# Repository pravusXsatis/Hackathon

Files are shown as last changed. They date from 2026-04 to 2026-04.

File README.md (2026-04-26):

# CPR Trainer — IDEA Hacks 2026

> **Theme: A Brighter Tomorrow** | **Subcategory: Educate the Future**
>
> Affordable, hands-on CPR practice: anywhere, anytime, no mannequin required.
>
> ⚠️ Training only — not a certified medical device.

---

## Inspiration

Cardiac arrest strikes more than 350,000 people outside of hospitals in the United States every year. Immediate bystander CPR can double or triple a victim's chance of survival, yet the vast majority of people have never practiced it. The barrier isn't awareness; it's access. Certified CPR training requires scheduling a class, traveling to a facility, and working with expensive mannequins that cost hundreds to thousands of dollars per unit.

We built the CPR Trainer to remove that barrier entirely. It is a wrist-worn device that turns any springy surface, like a couch cushion, a foam mat, a folded blanket, into a CPR practice station. A user connects their phone to the device's own Wi-Fi network, opens the dashboard in a browser, and receives real-time, per-compression coaching with zero setup friction and zero ongoing cost. This project gives hands-on CPR practice on a low cost portable setup.

---

## Why This Is an "Educate the Future" Project

- **Enhances how people learn CPR.** Rather than watching a video or attending a one-time class, the user gets immediate, quantified feedback on every compression, rate, force, and full release, forming correct muscle memory through repetition.
- **Integrates into daily life.** The device requires no mannequin, no facility, and no internet connection. Practice happens wherever someone already is, with the phone already in their pocket.
- **Unique educational approach.** A calibration step personalizes the feedback thresholds to the individual user and surface. This makes the coaching adaptive, not one-size-fits-all.
- **Intuitive and engaging.** The dashboard opens instantly in any browser. The guided calibration walks users through setup in under 30 seconds with a countdown UI. Feedback is immediate, plain-language, and per-compression.

---

## What It Does

The CPR Trainer wristband reads an FSR (Force-Sensitive Resistor) and ADXL335 accelerometer on an ESP32. The ESP32 broadcasts its own Wi-Fi access point, named `CPR_Trainer` (password: `cpr2026!`); the user connects their phone or laptop to that network and opens the on-device dashboard at `http://192.168.4.1` — no app install, no internet. The dashboard reads live data and shows rate, relative force, and motion quality.

### Live feedback on every compression

| Label | What it means |
|---|---|
| **Good compression** | Peak force is within the user's calibrated target range |
| **Push harder** | Peak force is below 60 % of the calibrated target |
| **Too hard** | Peak force exceeds 130 % of the calibrated target |
| **Release fully** | Force did not drop back to baseline — leaning detected |
| **Start compressions** | Idle state, ready to begin |

### Dashboard at a glance

- **Compression rate gauge** — live CPM needle against the AHA target band of 100–120 CPM
- **Relative-force trend graph** — scrolling plot of the last 100 force readings with a target-force reference line
- **Metric cards** — compression count, rate, raw force, relative force, target force, and recoil threshold
- **Motion quality score** — sum of corrected accelerometer magnitudes (|X| + |Y| + |Z|) as a wrist-form indicator
- **Guided calibration modal** — 3-step flow with countdown UI, "Ready / Set / Go" cues, and recoil confirmation

---

## How We Built It

### Hardware

| Component | Detail |
|---|---|
| ESP32 | Microcontroller, Wi-Fi access point, web server |
| Adafruit Square FSR (via voltage divider) | Compression force sensing on GPIO 36 |
| ADXL335 Accelerometer | Motion quality on GPIO 34, 32, 33 |
| Battery Pack | Increases project portability |

### Software Stack

| Layer | Technology | Source |
|---|---|---|
| Active runtime | Arduino C++ + ESP32 WebServer + DNSServer | `firmware/esp32_cpr_trainer.ino` |
| Legacy backend (reference) | Python / FastAPI + pyserial | `legacy/backend/main.py` |
| Legacy frontend (reference) | React + Vite | `legacy/frontend/src/App.jsx` |

The active demo is fully standalone on the ESP32: it hosts the dashboard at `/`, serves live metrics from `/data`, and handles calibration routes directly on-device (`/calibrate/rest`, `/calibrate/target`). The Python/React host-computer pipeline remains in `legacy/` for comparison and rollback experiments.

### 3-Step Guided Calibration

The calibration modal walks the user through setup before each session:

1. **Rest baseline** — captures resting baselines for force and all accelerometer channels.
2. **Target setup** — applies the current fixed force coaching target used by the firmware.
3. **Recoil confirmation** — checks that force returns close to baseline so release can be detected reliably.

### Compression Detection (inside `firmware/esp32_cpr_trainer.ino`)

- **Enter** compression when corrected force rises above a start threshold (`max(300, forceTarget * 0.45)` after target calibration).
- **Count** a compression when corrected force drops below the release threshold (`max(30, forceTarget * 0.15)`), with a 250 ms debounce guard.
- **Rate** is computed from compression events in a 5-second window.
- **Force feedback** uses fixed raw-force guidance bands for "Push harder" / "Good compression" / "Too hard".
- **Rate feedback** uses AHA guidance bands: `<100` too slow, `100-120` good rate, `>120` too fast.

> ⚠️ Training feedback only — not a certified medical device.

### Compression Quality Logic
 
| Condition | Feedback |
|---|---|
| Compression peak below firmware force window | Push harder |
| Compression peak within firmware force window | Good compression |
| Compression peak above firmware force window | Too hard |
| Force remains above recoil threshold right after release | Release fully |
| Rate below 100 CPM | Too slow |
| Rate from 100 through 120 CPM | Good rate |
| Rate above 120 CPM | Too fast |

---

## Accomplishments We're Proud Of

- **Adaptive calibration** — thresholds are personalized per user and per surface, so feedback is meaningful whether someone is pressing on a firm foam mat or a soft cushion.
- A software architecture designed from the start to run standalone on the ESP32 — no PC, no router, no cloud — so the finished device will be truly self-contained.

---

## Vibe Coding — AI-Assisted Development

The active firmware plus earlier host-computer prototypes (`legacy/backend` and `legacy/frontend`) were generated with heavy AI assistance using multiple LLM tools throughout the hackathon. This section documents both the benefits and the concrete obstacles we ran into, per the DigiKey challenge documentation requirement.

### What worked well

Using LLMs to scaffold both the standalone firmware flow and earlier host-computer prototypes in a single hackathon session was only feasible because of AI assistance. Initial working versions of the Arduino sampling and calibration flow, dashboard rendering logic, and legacy FastAPI/React pipeline were all generated from natural-language prompts, giving the team a running start rather than a blank file.

### Obstacles with AI-generated code

**1. Graph scaling math**
The AI-generated force graph component produced visually incorrect output. The coordinate mapping did not correctly normalize force values to the graph's dimensions, causing the y-axis scaling to be inverted in edge cases. The AI consistently regenerated versions with the same underlying error when prompted generically. Fixing it required us to manually work through the coordinate math and explicitly specify the correct formula in the prompt.
 
**2. Calibration state flow**
AI-generated calibration logic did not correctly sequence the rest, target, and recoil confirmation states. State transitions fired prematurely or skipped steps under certain timing conditions. The team had to manually trace the state machine and rewrite the transition guards to make the flow reliable.
 
**3. Timeout control**
AI-generated timeout handling in the calibration and data polling loops did not account for edge cases where the ESP32 response was slow. The team manually adjusted timeout durations and added fallback handling to keep the dashboard responsive under real hardware conditions.

---

## Challenges We Ran Into

We spent time deciding between three architectures: USB serial with Python backend, Bluetooth, and standalone ESP32 Wi-Fi. USB serial gave strong debug visibility, but added laptop setup steps for users. Bluetooth reduced wires, but browser support and pairing flow added friction for a fast demo. We moved back to standalone ESP32 Wi-Fi with captive portal because setup stayed simple and repeatable.
 
We also worked through reliability issues while serving both dashboard and live `/data` responses from one ESP32. Calibration flow started as technical, then we rewrote it into a guided rest and target sequence using `/calibrate/rest` and `/calibrate/target`. FSR threshold tuning required repeated tests because sensor values are relative and shift with strap tension, hand position, and surface type. We avoided claiming exact compression depth in centimeters because accelerometer integration drift can accumulate error over time.

---

## What We Learned

- How to configure ESP32 as a Wi-Fi access point named `CPR_Trainer` and route captive portal traffic with `DNSServer`.
- How a browser dashboard can talk to an embedded device through simple HTTP endpoints like `/data` and calibration routes.
- How to combine FSR force data and ADXL335 motion data for relative compression quality, rate, recoil, and motion quality feedback.
- That calibration and threshold tuning matter as much as UI polish for trustworthy coaching behavior.
- That keeping active code and experimental legacy code separated helps development move faster and keeps responsibilities clear.

---

## What's Next for CPR Trainer

- Improve calibration flow with more guided testing prompts and clearer completion checks.
- Tune force thresholds across more users and more surfaces to improve consistency.
- Add stronger recoil detection logic for edge cases where users keep slight pressure after release.
- Evaluate adding a true distance sensor if future versions require exact compression depth measurement.
- Improve enclosure and wristband comfort for longer practice sessions.
- Add data logging and session summaries so users can review progress over time.
- Improve mobile dashboard layout for smaller screens and faster one-hand use.
- Utilize more various sensors to standardize sufficient force for chest compressions.
- Provide alternative languages in the UI for expanded accesibility.

---

## Repository Structure

```
CPR-Trainer/
  firmware/
    esp32_cpr_trainer.ino   # ESP32 standalone AP + ADXL335/FSR coaching dashboard
  hardware/
    board/                  # KiCad board/schematic source files
    README.md               # KiCad schematic notes and image
  legacy/
    backend/main.py         # Earlier USB-serial FastAPI prototype
    frontend/src/App.jsx    # Earlier React dashboard prototype
```

### Legacy Folder

The `legacy/` folder keeps the earlier laptop-hosted architecture used before the fully standalone ESP32 captive-portal flow. It includes an older FastAPI backend and React frontend that read CPR data over USB serial from a separate host machine. Keep it for reference, comparisons, and rollback experiments, but use `firmware/esp32_cpr_trainer.ino` as the primary demo path for current development.

---

## Quick Start (Standalone Firmware)

### 1 — Flash the ESP32

1. Open `firmware/esp32_cpr_trainer.ino` in Arduino IDE.
2. Install the **ESP32** board package.
3. Wire sensors:
   - FSR analog output -> **GPIO 36**
   - ADXL335 XOUT -> **GPIO 34**
   - ADXL335 YOUT -> **GPIO 32**
   - ADXL335 ZOUT -> **GPIO 33**
   - Optional metronome LED -> **GPIO 18** (through resistor to GND)
4. Flash. Confirm serial output at **115200 baud**:
   ```json
   {"t":12345,"force":1842,"ax":0.02,"ay":0.11,"az":1.21}
   ```

### 2 — Connect and Run

```bash
Connect your phone or laptop to Wi-Fi SSID "CPR_Trainer" (password: cpr2026!)
Open http://192.168.4.1 in a browser
```

The dashboard and coaching logic are served directly by the ESP32. No laptop backend is required for the active demo.

### Legacy Host-Computer Flow (Optional)

```bash
# Backend
cd legacy/backend
python -m venv .venv
.venv\Scripts\Activate.ps1   # PowerShell
pip install -r requirements.txt
uvicorn main:app --reload --port 8000

# Frontend (second terminal)
cd legacy/frontend
npm install
npm run dev
```

Then open [http://localhost:5173](http://localhost:5173) in a browser.

For first-time learners, use this CPR basics video: [https://youtu.be/VZqG-tcZvfE?si=8la3IrQzfen--zav&t=35](https://youtu.be/VZqG-tcZvfE?si=8la3IrQzfen--zav&t=35). For in-person demos, print a QR code for the same link as a separate card/poster.

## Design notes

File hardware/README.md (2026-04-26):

# Hardware

This folder contains hardware documentation for the CPR Trainer, including the KiCad schematic project and exported images used for demos.

## Contents

- `schematic.png` - exported circuit schematic preview
- KiCad project files - editable source files for wiring/schematic updates

## Notes

- The active firmware pin mapping is documented in `firmware/README.md`.
- Use this folder as the single source of truth for hardware wiring revisions.

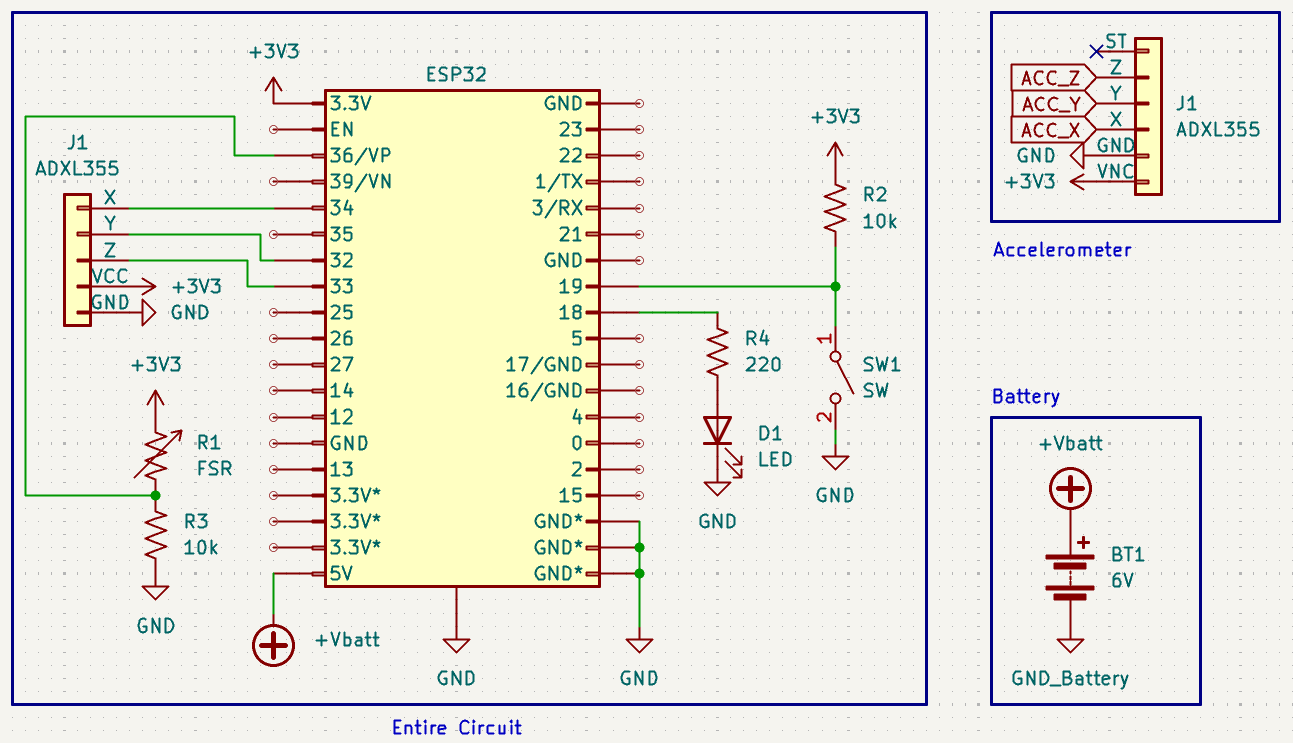
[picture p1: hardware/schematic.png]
Circuit Schematic


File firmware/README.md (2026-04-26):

# ESP32 Firmware

Primary firmware for the current standalone CPR Trainer demo.

Board: ESP32 Dev Module  
Upload baud: 115200 or 921600  
Serial Monitor baud: 115200

## Wiring

- FSR signal -> GPIO36
- ADXL335 XOUT -> GPIO34
- ADXL335 YOUT -> GPIO32
- ADXL335 ZOUT -> GPIO33
- ADXL335 VCC -> 3.3V
- ADXL335 GND -> GND
- FSR divider: 3.3V -> FSR -> GPIO36 -> 10k ohm -> GND
- LED metronome guide: GPIO18 -> 220 ohm resistor -> LED anode, LED cathode -> GND

## Power Switch and LED Assumptions

- The physical switch is intended to be a hardware power ON/OFF switch.
- The switch is not used as a calibration button in firmware.
- The GPIO18 LED is a software-controlled metronome pacing guide (about 110 BPM), not a true "correct BPM" indicator from measured user rate.
- If you want a true always-on power LED, wire it directly from 3.3V through a resistor to GND (not through a GPIO pin).

## Standalone Demo

The ESP32 creates a Wi-Fi access point:

```text
CPR_Trainer
```

Password:

```text
cpr2026!
```

Connect a phone or laptop to that network. The captive portal should open automatically. If it does not, visit:

```text
http://192.168.4.1
```

This is the current recommended architecture. The older host-computer flow is preserved in `legacy/`.

## CPR Learning Link

- Watch CPR basics: [https://youtu.be/VZqG-tcZvfE?si=8la3IrQzfen--zav&t=35](https://youtu.be/VZqG-tcZvfE?si=8la3IrQzfen--zav&t=35)
- For demos, print a QR code for that link as a separate handout card.

## Endpoints

- `GET /`
- `GET /data`
- `GET /calibrate/rest`
- `GET /calibrate/target`
- `GET /calibrate` (legacy alias of `/calibrate/rest`)

The firmware also handles common captive portal probe routes and unknown routes by serving the dashboard.

`GET /data` includes `ledMode` as `metronome_110` for the pacing guide LED mode.

## Legacy Note

If you need the previous laptop-hosted pipeline (USB serial -> FastAPI -> React), see the `legacy/` folder in the repository root. Use this firmware README for active hardware demos and current development.

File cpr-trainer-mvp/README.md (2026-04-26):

# Portable CPR Trainer

Standalone ESP32 CPR trainer demo. The ESP32 creates its own Wi-Fi network, opens a captive portal, serves the dashboard, and provides live sensor data directly from the board.

This project uses relative training feedback only: force, rate, recoil, and motion quality. It does not claim exact compression depth in centimeters.

## Main Demo Architecture

```text
ESP32 SoftAP "CPR_Trainer"
        |
        v
Phone/laptop joins ESP32 Wi-Fi
        |
        v
Captive portal opens dashboard from http://192.168.4.1
        |
        v
Dashboard polls ESP32 endpoints directly
```

The main demo does not depend on USB serial data streaming, Python backend services, localhost, or `127.0.0.1`.

## Repo Structure

```text
cpr-trainer-mvp/
  firmware/
    esp32_cpr_trainer.ino
  frontend/
    index.html
    package.json
    vite.config.js
    src/
      App.jsx
      main.jsx
      styles.css
  backend/
    main.py
    requirements.txt
```

## Hardware Wiring

- FSR voltage divider midpoint -> GPIO33
- ADXL335 XOUT -> GPIO34
- ADXL335 YOUT -> GPIO35
- ADXL335 ZOUT -> GPIO32
- ADXL335 VCC -> 3.3V
- ADXL335 GND -> GND
- FSR divider example: `3.3V -> FSR -> GPIO33 -> 10k ohm -> GND`

## Upload Firmware

1. Open `firmware/esp32_cpr_trainer.ino` in Arduino IDE.
2. Select an ESP32 board, such as **ESP32 Dev Module**.
3. Upload the sketch.
4. Open Serial Monitor at `115200` if you want to confirm startup logs.

Required Arduino libraries are included with the ESP32 Arduino core:

- `WiFi.h`
- `WebServer.h`
- `DNSServer.h`

## Run The Demo

1. Power the ESP32.
2. Connect your phone or laptop to Wi-Fi network `CPR_Trainer` with password `cprtrainer2026` (WPA2).
3. The captive portal should open automatically.
4. If it does not open, manually visit:

```text
http://192.168.4.1
```

The ESP32 serves the dashboard from `GET /`.
The SoftAP is limited to **2 simultaneous client connections**, which helps keep `/data` polling responsive during the live demo.

## Captive Portal

The firmware starts a DNS server and redirects unknown DNS/browser requests to the ESP32 SoftAP IP, normally `192.168.4.1`.

Captive portal routes include:

- `GET /generate_204`
- `GET /hotspot-detect.html`
- `GET /ncsi.txt`
- `GET /connecttest.txt`

Unknown routes serve the dashboard instead of returning `404`.

## ESP32 Endpoints

The dashboard reads directly from the ESP32:

- `GET /`
- `GET /data`
- `GET /calibrate/rest`
- `GET /calibrate/target`

JSON endpoints include CORS headers.

`GET /data` returns:

- `time`
- `forceRaw`
- `forceCorrected`
- `forceVoltage`
- `forceRestBaseline`
- `forceTarget`
- `accelXRaw`
- `accelYRaw`
- `accelZRaw`
- `accelXCorrected`
- `accelYCorrected`
- `accelZCorrected`
- `accelXVoltage`
- `accelYVoltage`
- `accelZVoltage`
- `motionMagnitude`
- `compressionCount`
- `compressionRate`
- `rateFeedback`
- `forceFeedback`
- `restCalibrated`
- `targetCalibrated`

## Guided Calibration

The dashboard guides the user through:

1. **Rest baseline**: "Place the trainer flat and do not press down."
   After a 3-second countdown, the dashboard calls `GET /calibrate/rest`.
2. **Target effort**: "Press down with what feels like a good CPR compression and hold."
   After a 3-second countdown, the dashboard calls `GET /calibrate/target`.
3. **Recoil check**: "Release fully."
   The dashboard polls `GET /data` until `forceCorrected` is close to `0`, then shows calibration complete.

## Frontend Development

The ESP32 firmware already serves the main demo dashboard. The React/Vite frontend is for local UI development.

When the React app is served by the ESP32, it uses relative URLs:

- `/data`
- `/calibrate/rest`
- `/calibrate/target`

When running the React app locally with Vite, it falls back to `http://192.168.4.1` unless `VITE_DEVICE_BASE` is set.

From `frontend/`:

```powershell
npm install
npm.cmd run dev -- --host 127.0.0.1
```

Then open:

```text
http://127.0.0.1:5173
```

Make sure your computer is connected to `CPR_Trainer` Wi-Fi so the local dev app can reach `http://192.168.4.1`.

Optional override:

```powershell
$env:VITE_DEVICE_BASE="http://192.168.4.1"
npm.cmd run dev -- --host 127.0.0.1
```

## Optional Legacy/Dev Backend

The Python backend is not part of the main submission/demo path. It is only an optional development fallback for simulation or older USB-serial workflows.

Use it only when the ESP32 hardware is unavailable or when you deliberately want a simulator:

```powershell
cd backend
python -m venv .venv
.\.venv\Scripts\python.exe -m pip install -r requirements.txt
$env:CPR_SIMULATOR="1"
.\.venv\Scripts\python.exe -m uvicorn main:app --port 8000
```

If using the optional backend with the React dev app:

```powershell
$env:VITE_DEVICE_BASE="http://127.0.0.1:8000"
npm.cmd run dev -- --host 127.0.0.1
```

Again: this backend mode is optional legacy/dev mode, not the standalone ESP32 demo path.

## Notes

- This is for training/demo use only and is not a medical device.
- Feedback is relative to the user's calibration and sensor readings.
- The FSR force signal is a proxy for compression effort, not exact chest depth.

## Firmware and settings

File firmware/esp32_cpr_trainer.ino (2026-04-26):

#include <DNSServer.h>
#include <WebServer.h>
#include <WiFi.h>

static const char* AP_SSID = "CPR_Trainer";
static const char* AP_PASSWORD = "cpr2026!";
static const int AP_CHANNEL = 1;
static const bool AP_HIDDEN = false;
static const int AP_MAX_CONNECTIONS = 2;
static const byte DNS_PORT = 53;
static const IPAddress AP_IP(192, 168, 4, 1);
static const IPAddress AP_GATEWAY(192, 168, 4, 1);
static const IPAddress AP_SUBNET(255, 255, 255, 0);

// Sensors
static const int FORCE_PIN = 36;  // FSR voltage divider midpoint
static const int ACCEL_X_PIN = 34; // ADXL335 XOUT
static const int ACCEL_Y_PIN = 32; // ADXL335 YOUT
static const int ACCEL_Z_PIN = 33; // ADXL335 ZOUT
static const int LED_PIN = 18; // Optional CPR metronome guide LED (GPIO18 -> resistor -> LED -> GND)

// Tunable CPR demo thresholds. These are relative-force thresholds, not depth.
static const int DEFAULT_FORCE_TARGET = 4000; // Fixed raw-force guidance target
static const int DEFAULT_START_THRESHOLD = 300;
static const int MIN_FORCE_TARGET = 100;
static const int RECOIL_THRESHOLD = 30;
static const int FIXED_FORCE_MIN_RAW = 3500;
static const int FIXED_FORCE_MAX_RAW = 4500;
static const int ADC_MAX_RAW = 4095;
static const int FIXED_FORCE_MAX_EFFECTIVE = ADC_MAX_RAW; // ESP32 ADC max
static const unsigned long COMPRESSION_DEBOUNCE_MS = 250;
static const unsigned long RATE_WINDOW_MS = 5000;
static const int MAX_RATE_EVENTS = 48;
static const unsigned long LED_METRONOME_INTERVAL_MS = 545; // ~110 BPM pacing guide
static const unsigned long LED_METRONOME_ON_MS = 110;
static const bool ENABLE_SERIAL_MONITOR_TELEMETRY = true;
static const unsigned long SERIAL_TELEMETRY_INTERVAL_MS = 250;

DNSServer dnsServer;
WebServer server(80);

int forceRestBaseline = 0;
int forceTarget = DEFAULT_FORCE_TARGET;
int accelXBaseline = 0;
int accelYBaseline = 0;
int accelZBaseline = 0;

bool restCalibrated = false;
bool targetCalibrated = false;

bool inCompression = false;
int activeCompressionPeak = 0;
int lastCompressionPeak = 0;
int activeCompressionPeakRaw = 0;
int lastCompressionPeakRaw = 0;
int compressionCount = 0;
unsigned long lastCompletedCompressionMs = 0;
float compressionRate = 0.0;
unsigned long compressionEventTimesMs[MAX_RATE_EVENTS];
int compressionEventCount = 0;
String lastForceFeedback = "Start compressions";

enum LedMode { LED_MODE_METRONOME_110 };

LedMode ledMode = LED_MODE_METRONOME_110;
bool ledOutputHigh = false;
unsigned long lastSerialTelemetryMs = 0;

const char DASHBOARD_HTML[] PROGMEM = R"rawliteral(
<!doctype html>
<html lang="en">
<head>
  <meta charset="utf-8">
  <meta name="viewport" content="width=device-width, initial-scale=1">
  <title>CPR Coach</title>
  <style>
    :root {
      font-family: Inter, system-ui, -apple-system, BlinkMacSystemFont, "Segoe UI", sans-serif;
      color: #eef6f8;
      background: #101417;
    }

    * { box-sizing: border-box; }
    body {
      margin: 0;
      min-height: 100vh;
      background: linear-gradient(180deg, rgba(23,34,38,.94), rgba(12,15,17,.98));
    }
    button, input { font: inherit; }
    .app {
      width: min(1120px, 100%);
      margin: 0 auto;
      padding: 16px;
      display: grid;
      gap: 14px;
    }
    .topbar, .control-bar, .rate-head, .graph-head {
      display: flex;
      align-items: center;
      justify-content: space-between;
      gap: 12px;
    }
    .topbar { min-height: 64px; }
    .eyebrow {
      margin: 0 0 3px;
      color: #8fd0c1;
      font-size: .78rem;
      font-weight: 800;
      text-transform: uppercase;
    }
    h1, h2, p { margin-top: 0; }
    h1 {
      margin-bottom: 0;
      font-size: clamp(1.8rem, 5vw, 3.4rem);
      line-height: .95;
    }
    .status {
      border-radius: 999px;
      padding: 8px 12px;
      background: #0f4a32;
      color: #bcffdc;
      font-size: .85rem;
      font-weight: 800;
      white-space: nowrap;
    }
    .control-bar {
      flex-wrap: wrap;
      justify-content: flex-start;
      padding: 10px;
      border: 1px solid rgba(185,203,204,.22);
      border-radius: 8px;
      background: rgba(18,24,27,.86);
    }
    button {
      min-height: 42px;
      border: 0;
      border-radius: 8px;
      padding: 10px 14px;
      background: #0f9f79;
      color: white;
      font-weight: 800;
      cursor: pointer;
    }
    button:disabled { opacity: .6; cursor: default; }
    .voice-toggle {
      margin-left: auto;
      display: inline-flex;
      align-items: center;
      gap: 9px;
      color: #dbe8e9;
      font-weight: 750;
      cursor: pointer;
    }
    .voice-toggle input {
      width: 20px;
      height: 20px;
      accent-color: #10b981;
    }
    .info-card {
      border: 1px solid rgba(185,203,204,.22);
      border-radius: 8px;
      background: rgba(18,24,27,.9);
      padding: 14px;
    }
    .info-card h2 {
      margin: 0 0 8px;
      font-size: clamp(1.05rem, 3vw, 1.35rem);
    }
    .how-list {
      margin: 0;
      padding-left: 20px;
      color: #dbe8e9;
      line-height: 1.4;
    }
    .feedback-card, .rate-panel, .metric-card, .graph-card, .motion-card {
      border: 1px solid rgba(185,203,204,.22);
      border-radius: 8px;
      background: rgba(18,24,27,.9);
      box-shadow: 0 16px 40px rgba(0,0,0,.22);
    }
    .feedback-card {
      min-height: 160px;
      display: grid;
      align-content: center;
      padding: clamp(18px, 4vw, 34px);
      border-left-width: 8px;
    }
    .feedback-card.good { border-left-color: #12d18e; }
    .feedback-card.warn { border-left-color: #ffc857; }
    .feedback-card.alert { border-left-color: #ff5b57; }
    .feedback-card.idle { border-left-color: #70a7ff; }
    .label, .metric-title {
      margin-bottom: 6px;
      color: #abc0c2;
      font-size: .84rem;
      font-weight: 800;
      text-transform: uppercase;
    }
    .feedback-message {
      margin-bottom: 8px;
      font-size: clamp(2.4rem, 8vw, 5.8rem);
      line-height: .95;
      font-weight: 900;
    }
    .feedback-cue {
      margin-bottom: 0;
      color: #d9e5e7;
      font-weight: 650;
    }
    .trainer-grid {
      display: grid;
      grid-template-columns: 1fr;
      gap: 12px;
    }
    .rate-panel, .motion-card, .graph-card, .metric-card { padding: 14px; }
    .rate-head p, .graph-head h2, .graph-head span { margin-bottom: 0; }
    .rate-head p {
      color: #abc0c2;
      font-size: .84rem;
      font-weight: 800;
      text-transform: uppercase;
    }
    .rate-head strong { font-size: clamp(1.5rem, 4vw, 2.5rem); }
    .rate-track {
      position: relative;
      height: 44px;
      margin-top: 18px;
      border-radius: 8px;
      background: linear-gradient(90deg, #5e3030 0%, #7a5f20 58%, #126846 67%, #126846 80%, #7a5f20 90%, #5e3030 100%);
      overflow: hidden;
    }
    .target-zone {
      position: absolute;
      inset: 0 20% 0 66.666%;
      border-inline: 2px solid rgba(255,255,255,.74);
    }
    .rate-needle {
      position: absolute;
      top: 4px;
      bottom: 4px;
      width: 4px;
      transform: translateX(-2px);
      border-radius: 4px;
      background: #fff;
      box-shadow: 0 0 0 3px rgba(0,0,0,.2);
    }
    .rate-scale {
      position: relative;
      height: 22px;
      margin-top: 8px;
      color: #abc0c2;
      font-size: .78rem;
      font-weight: 750;
    }
    .rate-scale span { position: absolute; top: 0; transform: translateX(-50%); }
    .rate-scale span:first-child { transform: none; }
    .rate-scale span:last-child { transform: translateX(-100%); }
    .metrics-grid {
      display: grid;
      grid-template-columns: repeat(2, minmax(0, 1fr));
      gap: 10px;
    }
    .metric-card { min-width: 0; overflow: hidden; }
    .metric-value {
      margin-bottom: 0;
      font-size: clamp(1.55rem, 4vw, 2.3rem);
      line-height: 1.05;
      font-weight: 900;
      overflow-wrap: anywhere;
    }
    .score-note {
      margin: 8px 0 0;
      color: #9fb4b7;
      font-size: .88rem;
      line-height: 1.35;
    }
    .graph-head span { color: #9fb4b7; font-size: .86rem; font-weight: 700; }
    .graph-wrap {
      margin-top: 10px;
      height: 260px;
      border-radius: 8px;
      border: 1px solid rgba(185,203,204,.2);
      background: #0b1012;
      overflow: hidden;
    }
    canvas { width: 100%; height: 100%; display: block; }
    .modal {
      position: fixed;
      inset: 0;
      display: none;
      place-items: center;
      padding: 16px;
      background: rgba(3,7,9,.82);
      z-index: 10;
    }
    .modal.open { display: grid; }
    .modal-card {
      width: min(680px, 100%);
      border-radius: 12px;
      border: 1px solid rgba(185,203,204,.28);
      background: rgba(18,24,27,.97);
      padding: clamp(18px, 4vw, 34px);
    }
    .modal-card h2 {
      margin: 8px 0 0;
      font-size: clamp(1.35rem, 4vw, 2.15rem);
      line-height: 1.2;
    }
    .phase {
      margin: 12px 0 0;
      color: #9ddfcb;
      font-weight: 800;
    }
    .countdown {
      margin: 14px 0 0;
      color: #8df6d0;
      font-size: clamp(2.4rem, 11vw, 5rem);
      font-weight: 900;
      line-height: 1;
    }
    @media (min-width: 760px) {
      .app { padding: 24px; gap: 16px; }
      .trainer-grid { grid-template-columns: minmax(0, 1.2fr) minmax(320px, .8fr); }
      .metrics-grid { grid-template-columns: repeat(4, minmax(0, 1fr)); }
    }
    @media (max-width: 560px) {
      .topbar { align-items: flex-start; flex-direction: column; }
      .voice-toggle { width: 100%; margin-left: 0; }
      button { flex: 1 1 150px; }
      .metrics-grid { grid-template-columns: 1fr; }
    }
  </style>
</head>
<body>
  <main class="app">
    <header class="topbar">
      <div>
        <p class="eyebrow">Portable Trainer</p>
        <h1>CPR Coach</h1>
      </div>
      <span id="status" class="status">ESP32 Wi-Fi Live</span>
    </header>

    <section class="control-bar">
      <button id="calibrateBtn" type="button">Start Guided Calibration</button>
      <label class="voice-toggle">
        <input id="voiceToggle" type="checkbox">
        <span>Voice prompts</span>
      </label>
    </section>

    <section class="info-card" aria-label="How to Wear the Trainer">
      <h2>How to Wear the Trainer</h2>
      <ol class="how-list">
        <li>Put the workout strap on your right hand.</li>
        <li>Wrap the strap around your wrist and loop it over your thumb.</li>
        <li>Place the red square sensor between the practice surface and the bottom of your palm.</li>
        <li>Keep the red square under your palm during compressions.</li>
      </ol>
    </section>

    <section id="feedbackCard" class="feedback-card idle">
      <p class="label">Compression Quality</p>
      <p id="qualityFeedback" class="feedback-message">Start compressions</p>
      <p id="feedbackCue" class="feedback-cue">Begin when ready.</p>
    </section>

    <section class="trainer-grid">
      <section class="rate-panel">
        <div class="rate-head">
          <p>Compression Rate</p>
          <strong id="rateValue">0.0 CPM</strong>
        </div>
        <div class="rate-track">
          <span class="target-zone"></span>
          <span id="rateNeedle" class="rate-needle" style="left:0%"></span>
        </div>
        <div class="rate-scale">
          <span style="left:0%">0</span>
          <span style="left:66.666%">100</span>
          <span style="left:80%">120</span>
          <span style="left:100%">150</span>
        </div>
      </section>

      <article class="motion-card">
        <p class="label">Motion Quality</p>
        <p id="motionMagnitude" class="metric-value">0</p>
        <p class="score-note">Relative movement from ADXL335 X/Y/Z channels.</p>
      </article>
    </section>

    <section class="metrics-grid">
      <article class="metric-card"><p class="metric-title">Compression Count</p><p id="compressionCount" class="metric-value">0</p></article>
      <article class="metric-card"><p class="metric-title">Compression Rate</p><p id="compressionRateCard" class="metric-value">0.0 CPM</p></article>
      <article class="metric-card"><p class="metric-title">Rate Feedback</p><p id="rateFeedback" class="metric-value">-</p></article>
      <article class="metric-card"><p class="metric-title">Force Feedback</p><p id="forceFeedback" class="metric-value">-</p></article>
    </section>

    <section class="graph-card">
      <div class="graph-head">
        <h2>Compression Graph</h2>
        <span>live compression pressure pattern</span>
      </div>
      <div class="graph-wrap">
        <canvas id="forceCanvas"></canvas>
      </div>
    </section>
  </main>

  <section id="modal" class="modal" role="dialog" aria-modal="true">
    <div class="modal-card">
      <p id="modalStep" class="label">Step</p>
      <h2 id="modalDetail"></h2>
      <p id="modalPhase" class="phase"></p>
      <p id="modalCountdown" class="countdown"></p>
    </div>
  </section>

  <script>
    const MAX_POINTS = 100;
    const RELEASE_THRESHOLD = 30;
    const RELEASE_CLOSE_TO_ZERO_THRESHOLD = 12;
    const COMPRESSION_START_THRESHOLD = 45;
    const PUSH_HARDER_RATIO = 0.6;
    const TOO_HARD_RATIO = 1.3;
    const VOICE_COOLDOWN_MS = 3000;
    const LIVE_VOICE_PROMPTS = new Set(["Too fast", "Too slow", "Push harder", "Release fully", "Good rate"]);
    const state = {
      points: [],
      latest: null,
      compressionActive: false,
      peak: 0,
      lastCompletedAt: 0,
      qualityFeedback: "Start compressions",
      calibrationRunning: false,
      voiceEnabled: false,
      lastSpoken: "",
      lastSpokenAt: 0
    };

    const meta = {
      "Good compression": ["good", "Relative force is in target range."],
      "Good rate": ["good", "Keep compressions steady."],
      "Push harder": ["warn", "Peak force is below 60% of your calibrated target."],
      "Too slow": ["warn", "Speed up toward 100 to 120 compressions per minute."],
      "Too fast": ["warn", "Slow down toward 100 to 120 compressions per minute."],
      "Too hard": ["alert", "Peak force is above 130% of your calibrated target."],
      "Release fully": ["alert", "Do not lean between compressions."],
      "Calibrate target": ["warn", "Run guided calibration before training."],
      "Start compressions": ["idle", "Begin when ready."]
    };

    function $(id) { return document.getElementById(id); }
    function sleep(ms) { return new Promise(resolve => setTimeout(resolve, ms)); }
    function round(value) { return Math.round(Number(value) || 0); }

    async function fetchJson(path) {
      const response = await fetch(path, { cache: "no-store" });
      if (!response.ok) throw new Error(path + " failed");
      return response.json();
    }

    async function fetchJsonWithRetry(path, attempts = 3) {
      let lastError;
      for (let attempt = 1; attempt <= attempts; attempt++) {
        try {
          return await fetchJson(path);
        } catch (error) {
          lastError = error;
          if (attempt < attempts) {
            await sleep(180);
          }
        }
      }
      throw lastError || new Error(path + " failed");
    }

    function updateQuality(data) {
      const force = round(data.forceCorrected);
      const target = Math.max(0, round(data.forceTarget));
      if (force >= COMPRESSION_START_THRESHOLD && !state.compressionActive) {
        state.compressionActive = true;
        state.peak = force;
      }
      if (state.compressionActive) {
        state.peak = Math.max(state.peak, force);
        if (force <= RELEASE_THRESHOLD) {
          state.compressionActive = false;
          state.lastCompletedAt = Date.now();
          if (target > 0) {
            const ratio = state.peak / target;
            if (ratio < PUSH_HARDER_RATIO) state.qualityFeedback = "Push harder";
            else if (ratio > TOO_HARD_RATIO) state.qualityFeedback = "Too hard";
            else state.qualityFeedback = "Good compression";
          } else {
            state.qualityFeedback = "Calibrate target";
          }
          state.peak = 0;
        }
      }
      if (!state.compressionActive && force > RELEASE_THRESHOLD && Date.now() - state.lastCompletedAt < 1500) {
        state.qualityFeedback = "Release fully";
      }
    }

    function setFeedback(text) {
      const info = meta[text] || meta["Start compressions"];
      $("feedbackCard").className = "feedback-card " + info[0];
      $("qualityFeedback").textContent = text;
      $("feedbackCue").textContent = info[1];
    }

    function speakIfReady(prompt) {
      if (!state.voiceEnabled || state.calibrationRunning || !("speechSynthesis" in window)) return;
      if (!prompt || !LIVE_VOICE_PROMPTS.has(prompt)) return;
      const now = Date.now();
      if (prompt === state.lastSpoken && now - state.lastSpokenAt < VOICE_COOLDOWN_MS) return;
      window.speechSynthesis.cancel();
      const utterance = new SpeechSynthesisUtterance(prompt);
      utterance.rate = 1.05;
      utterance.pitch = 1.0;
      utterance.volume = 0.9;
      window.speechSynthesis.speak(utterance);
      state.lastSpoken = prompt;
      state.lastSpokenAt = now;
    }

    function drawGraph(target) {
      const canvas = $("forceCanvas");
      const rect = canvas.getBoundingClientRect();
      const scale = window.devicePixelRatio || 1;
      canvas.width = Math.max(1, Math.floor(rect.width * scale));
      canvas.height = Math.max(1, Math.floor(rect.height * scale));
      const ctx = canvas.getContext("2d");
      ctx.setTransform(scale, 0, 0, scale, 0, 0);
      ctx.clearRect(0, 0, rect.width, rect.height);

      const values = state.points;
      const maxObserved = Math.max(target, 100, ...values);
      const graphMax = Math.max(100, Math.ceil(maxObserved / 100) * 100);

      ctx.strokeStyle = "rgba(255,255,255,.08)";
      ctx.lineWidth = 1;
      for (let i = 1; i < 4; i++) {
        const y = rect.height * i / 4;
        ctx.beginPath();
        ctx.moveTo(0, y);
        ctx.lineTo(rect.width, y);
        ctx.stroke();
      }

      const targetY = rect.height - (Math.max(0, target) / graphMax) * rect.height;
      if (target > 0) {
        ctx.setLineDash([6, 6]);
        ctx.strokeStyle = "#ffc857";
        ctx.beginPath();
        ctx.moveTo(0, targetY);
        ctx.lineTo(rect.width, targetY);
        ctx.stroke();
        ctx.setLineDash([]);
        ctx.fillStyle = "#ffd36c";
        ctx.font = "800 13px system-ui";
        ctx.fillText("target " + target, 12, Math.max(16, targetY - 6));
      }

      ctx.strokeStyle = "#75e6ff";
      ctx.lineWidth = 3;
      ctx.beginPath();
      values.forEach((value, index) => {
        const x = values.length <= 1 ? 0 : index * rect.width / (values.length - 1);
        const y = rect.height - (Math.max(0, value) / graphMax) * rect.height;
        if (index === 0) ctx.moveTo(x, y);
        else ctx.lineTo(x, y);
      });
      ctx.stroke();

      ctx.fillStyle = "#abc0c2";
      ctx.font = "800 13px system-ui";
      ctx.textAlign = "right";
      ctx.fillText(String(graphMax), rect.width - 10, 18);
      ctx.fillText("0", rect.width - 10, rect.height - 10);
    }

    function render(data) {
      state.latest = data;
      const liveForceFeedback = String(data.forceFeedback || "Start compressions");
      state.qualityFeedback = liveForceFeedback;
      const relativeForce = round(data.forceCorrected);
      const target = round(data.forceTarget);
      state.points.push(relativeForce);
      state.points = state.points.slice(-MAX_POINTS);

      $("compressionCount").textContent = round(data.compressionCount);
      $("compressionRateCard").textContent = Number(data.compressionRate || 0).toFixed(1) + " CPM";
      $("rateValue").textContent = Number(data.compressionRate || 0).toFixed(1) + " CPM";
      $("motionMagnitude").textContent = round(data.motionMagnitude);
      $("rateFeedback").textContent = data.rateFeedback || "-";
      $("forceFeedback").textContent = data.forceFeedback || "-";

      const ratePercent = Math.max(0, Math.min(100, (Number(data.compressionRate || 0) / 150) * 100));
      $("rateNeedle").style.left = ratePercent + "%";

      setFeedback(liveForceFeedback);
      const voicePrompt = [data.rateFeedback, data.forceFeedback, state.qualityFeedback].find((text) => LIVE_VOICE_PROMPTS.has(text));
      speakIfReady(voicePrompt || "");
      drawGraph(target);
      $("status").textContent = "ESP32 Wi-Fi Live";
    }

    async function pollData() {
      try {
        const data = await fetchJson("/data");
        render(data);
      } catch (error) {
        $("status").textContent = "Waiting for ESP32";
      }
    }

    function setModal(open, step, detail, phase, countdown) {
      $("modal").className = open ? "modal open" : "modal";
      $("modalStep").textContent = step || "";
      $("modalDetail").textContent = detail || "";
      $("modalPhase").textContent = phase || "";
      $("modalCountdown").textContent = countdown == null ? "" : String(countdown);
    }

    async function countdown(step, detail, capturePath) {
      setModal(true, step, detail, "Read the instruction", null);
      await sleep(1500);
      for (const cue of ["Ready", "Set", "Go"]) {
        setModal(true, step, detail, cue, null);
        await sleep(700);
      }
      let captured = false;
      for (let value = 5; value > 0; value--) {
        setModal(true, step, detail, "Hold steady", value);
        if (capturePath && value === 1 && !captured) {
          // Keep "1" visible briefly before and during capture request.
          await sleep(250);
          setModal(true, step, detail, "Hold steady", 1);
          await fetchJsonWithRetry(capturePath, 3);
          captured = true;
          await sleep(250);
        } else {
          await sleep(1000);
        }
      }
    }
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
void loop() {
  dnsServer.processNextRequest();
  server.handleClient();
  updateStatusLed();
}

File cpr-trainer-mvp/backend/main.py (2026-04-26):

import asyncio
import json
import math
import os
import statistics
import threading
import time
from collections import deque
from typing import Any

import serial
from fastapi import FastAPI, WebSocket, WebSocketDisconnect
from fastapi.middleware.cors import CORSMiddleware
from pydantic import BaseModel


class SerialConfig(BaseModel):
  port: str = os.getenv("SERIAL_PORT", "COM3")
  baud: int = int(os.getenv("SERIAL_BAUD", "115200"))


SIMULATOR_ENABLED = os.getenv("CPR_SIMULATOR", "0").lower() in {"1", "true", "yes", "on"}
SIMULATOR_BASELINE_FORCE = 520.0
SIMULATOR_SAMPLE_INTERVAL_MS = 20
SIMULATOR_SCRIPT = [
  {"label": "Push harder", "duration_s": 9.0, "cpm": 110.0, "amplitude": 150.0, "release_offset": 0.0},
  {"label": "Too slow", "duration_s": 11.0, "cpm": 82.0, "amplitude": 760.0, "release_offset": 0.0},
  {"label": "Good rate", "duration_s": 13.0, "cpm": 110.0, "amplitude": 760.0, "release_offset": 0.0},
  {"label": "Too hard", "duration_s": 9.0, "cpm": 110.0, "amplitude": 1120.0, "release_offset": 0.0},
  {"label": "Too fast", "duration_s": 11.0, "cpm": 136.0, "amplitude": 760.0, "release_offset": 0.0},
  {"label": "Release fully", "duration_s": 12.0, "cpm": 110.0, "amplitude": 760.0, "release_offset": 38.0},
]


class CalibrationState(BaseModel):
  running: bool = False
  started_at_ms: int = 0
  duration_ms: int = 3000


class CPRState:
  def __init__(self) -> None:
    self.reset_session()
    self.calibration = CalibrationState()

  def reset_session(self) -> None:
    self.baseline_force = 0.0
    self.max_force = 2500.0
    self.dynamic_threshold = 250.0
    self.last_force = 0.0
    self.in_compression = False
    self.last_compression_ms = -10_000
    self.debounce_ms = 250
    self.compression_count = 0
    self.releases_ok = 0
    self.intervals_ms: deque[float] = deque(maxlen=20)
    self.compression_times_ms: deque[float] = deque(maxlen=30)
    self.recent_force_scores: deque[float] = deque(maxlen=5)
    self.force_history: deque[dict[str, float]] = deque(maxlen=300)
    self.current_peak_force_above_baseline = 0.0
    self.last_feedback = "Push harder"
    self.last_metrics: dict[str, Any] = {}

  def start_calibration(self, duration_ms: int = 3000) -> None:
    self.calibration = CalibrationState(
      running=True,
      started_at_ms=int(time.time() * 1000),
      duration_ms=duration_ms,
    )
    self._cal_samples: list[float] = []

  def process_sample(self, sample: dict[str, Any]) -> dict[str, Any]:
    now_ms = float(sample.get("t", time.time() * 1000))
    force = float(sample.get("force", 0.0))

    self.force_history.append({"t": now_ms, "force": force})

    if self.calibration.running:
      self._cal_samples.append(force)
      elapsed = int(time.time() * 1000) - self.calibration.started_at_ms
      if elapsed >= self.calibration.duration_ms:
        self.calibration.running = False
        if self._cal_samples:
          self.baseline_force = float(statistics.fmean(self._cal_samples))
          p95 = sorted(self._cal_samples)[int(len(self._cal_samples) * 0.95)]
          self.max_force = max(self.baseline_force + 800.0, float(p95))
          self.dynamic_threshold = max(70.0, (self.max_force - self.baseline_force) * 0.12)

    force_above_baseline = max(0.0, force - self.baseline_force)
    threshold = self.baseline_force + self.dynamic_threshold

    # Compression detector:
    # 1) Enter compression when force rises above threshold.
    # 2) Count only once force falls back near baseline, with debounce guard.
    if not self.in_compression and force > threshold:
      self.in_compression = True

    release_threshold = self.baseline_force + max(40.0, self.dynamic_threshold * 0.4)
    if self.in_compression:
      self.current_peak_force_above_baseline = max(self.current_peak_force_above_baseline, force_above_baseline)

    if self.in_compression and force <= release_threshold:
      if now_ms - self.last_compression_ms >= self.debounce_ms:
        self.compression_count += 1
        if self.last_compression_ms > 0:
          self.intervals_ms.append(now_ms - self.last_compression_ms)
        self.compression_times_ms.append(now_ms)
        self.last_compression_ms = now_ms
        self.recent_force_scores.append(self._compute_force_score(self.current_peak_force_above_baseline))

        if force <= self.baseline_force + 30.0:
          self.releases_ok += 1
      self.in_compression = False
      self.current_peak_force_above_baseline = 0.0

    recent_cpm = self._compute_rate()
    rhythm_score = self._compute_rhythm_score()
    force_score = statistics.fmean(self.recent_force_scores) if self.recent_force_scores else self._compute_force_score(force_above_baseline)
    release_ratio = (self.releases_ok / self.compression_count) if self.compression_count > 0 else 1.0

    self.last_feedback = self._feedback_text(
      recent_cpm=recent_cpm,
      force_score=force_score,
      release_ratio=release_ratio,
    )

    metrics = {
      "compressionCount": self.compression_count,
      "compressionRate": recent_cpm,
      "forceLevel": force,
      "forceScore": force_score,
      "rhythmConsistency": rhythm_score,
      "releaseQuality": release_ratio,
      "baselineForce": self.baseline_force,
      "threshold": threshold,
      "feedback": self.last_feedback,
      "calibrating": self.calibration.running,
    }
    self.last_metrics = metrics
    return metrics

  def _compute_rate(self) -> float:
    if len(self.compression_times_ms) < 2:
      return 0.0
    elapsed_ms = self.compression_times_ms[-1] - self.compression_times_ms[0]
    if elapsed_ms <= 0:
      return 0.0
    return (len(self.compression_times_ms) - 1) * 60_000.0 / elapsed_ms

  def _compute_rhythm_score(self) -> float:
    if len(self.intervals_ms) < 3:
      return 1.0
    mean_interval = statistics.fmean(self.intervals_ms)
    if mean_interval <= 0:
      return 0.0
    std_dev = statistics.pstdev(self.intervals_ms)
    cv = std_dev / mean_interval
    return max(0.0, min(1.0, 1.0 - cv))

  def _compute_force_score(self, force_above_baseline: float) -> float:
    span = max(200.0, self.max_force - self.baseline_force)
    return max(0.0, min(1.0, force_above_baseline / span))

  def _feedback_text(self, recent_cpm: float, force_score: float, release_ratio: float) -> str:
    if release_ratio < 0.8:
      return "Release fully"
    if force_score < 0.25:
      return "Push harder"
    if recent_cpm < 100 and recent_cpm > 0:
      return "Too slow"
    if recent_cpm > 120:
      return "Too fast"
    if 100 <= recent_cpm <= 120:
      return "Good rate"
    return "Push harder"
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

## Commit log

2026-04-26 Fixed Calibration ? (need hardware to test)
    [main.py]
2026-04-26 Reorganize repo for standalone ESP32 demo
    [CPR_Trainer_Board.kicad_pcb, CPR_Trainer_Board.kicad_sch]
2026-04-26 Pre-merge README fix, updated GPIO Pins
    [CPR_Trainer_Board.kicad_sch]
